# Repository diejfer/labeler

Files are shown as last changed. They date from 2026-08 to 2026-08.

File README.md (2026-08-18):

# Labeler CNC - ESP32 DevKit V1

Control CNC de dos drivers STEP/DIR y un servo RC basado en FluidNC 4.0.3.

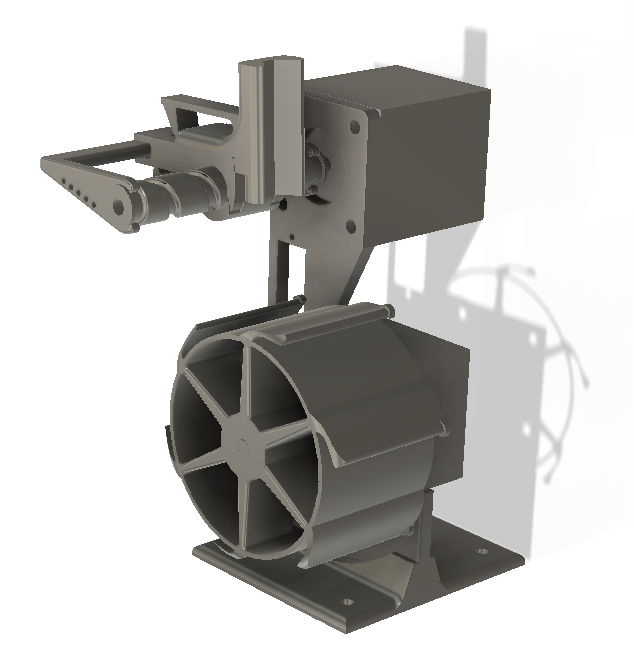
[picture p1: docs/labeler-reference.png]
Vista de referencia de la impresora de etiquetas


Esta es una impresora/plotter de etiquetas de dos ejes: X arrastra la cinta, Y
desplaza el marcador transversalmente y un servo lo apoya o lo separa. Este
repositorio contiene el firmware, la configuración del ESP32 y la aplicación
web que genera y envía el G-code.

## Demostración

Reproducir una demostración del Labeler en YouTube (https://youtu.be/mnnyJeXbWnY)

Hacer clic en la imagen para ver el breve video de la máquina en funcionamiento.

El proyecto PlatformIO activo está en `firmware/FluidNC`. El sketch Arduino
experimental anterior fue retirado para evitar cargar accidentalmente un
firmware sin planificador CNC.

## Estructura

- `firmware/FluidNC`: código fuente fijado a FluidNC v4.0.3.
- `firmware/esp32-data/config.yaml`: configuración de los ejes X, Y y A.
- `hardware/printable`: piezas STL listas para preparar en el laminador.
- `github-pages`: assets HTML, CSS y JavaScript para GitHub Pages.

## Piezas imprimibles

Los modelos exportados para impresión 3D están en `hardware/printable`:

- [`carroYinferior.stl`](hardware/printable/carroYinferior.stl)
- [`carroYsuperior.stl`](hardware/printable/carroYsuperior.stl)
- [`portalapiz.stl`](hardware/printable/portalapiz.stl)
- [`ejeZ.stl`](hardware/printable/ejeZ.stl)
- [`ejeY.stl`](hardware/printable/ejeY.stl)
- [`pie.stl`](hardware/printable/pie.stl)
- [`soportegeneral.stl`](hardware/printable/soportegeneral.stl)
- [`soportemotor.stl`](hardware/printable/soportemotor.stl)
- [`carreteCinta.stl`](hardware/printable/carreteCinta.stl)

Los STL contienen solamente la geometría. Antes de imprimir, revisar en el
laminador la orientación, soportes, relleno y cantidad necesaria de cada pieza
según el material y la impresora disponibles.

La aplicación se publica automáticamente en
`https://diejfer.github.io/labeler`, busca `http://labeler.local` mediante las
APIs REST y no depende de archivos web almacenados en el ESP32.

El navegador debe soportar Local Network Access y conceder permiso a GitHub
Pages para buscar dispositivos en la red local. La implementación apunta a
Chrome/Edge 142 o posterior. El ESP32 y el navegador deben estar en la misma
red Wi-Fi con mDNS habilitado.

La fuente incluida deriva de Hershey Roman Simplex. Los glifos originales
fueron creados por el Dr. A. V. Hershey en el U.S. National Bureau of Standards
y el formato JHF distribuido fue creado por James Hurt, Cognition, Inc. La
licencia y los datos originales están en `github-pages/vendor/hershey`.

También se incluyen Playwrite DE SAS Guides, Orbitron y las cuatro variantes
de Lobster Two desde el repositorio oficial de Google Fonts, bajo SIL OFL 1.1.
Los Material Symbols Outlined y su catálogo de nombres provienen del repositorio
oficial de Google y se distribuyen bajo Apache 2.0. `opentype.js` se utiliza
bajo licencia MIT para transformar los contornos tipográficos en recorridos.
Todas las licencias están junto a sus assets en `github-pages/vendor`.

## Aplicación de etiquetas

La interfaz permite seleccionar cintas de 6, 9, 12, 18, 24, 36 o 45 mm, o ingresar
un ancho particular. Puede generar etiquetas de uno o dos renglones. El texto
se convierte en recorridos mediante Hershey Roman Simplex, una fuente vectorial
estándar de trazo simple para plotters, con mayúsculas y minúsculas. También
permite elegir fuentes OpenType de Google Fonts, cuyos contornos Bézier se
aproximan mediante segmentos de precisión mecánica. El editor permite ajustar
el interlineado y aplicar negrita, cursiva y subrayado tanto a la vista previa
como al G-code, además de buscar e insertar cualquiera de los Material Symbols
Outlined disponibles mediante tokens como `{home}`.

El eje X corresponde al sentido longitudinal de la cinta, Y a su ancho y el eje
A al servo que acerca o aleja el marcador. Antes de imprimir se muestra el
G-code completo para inspección.

Los siguientes datos sólo existen en la pestaña actual del navegador y nunca se
guardan en el ESP32:

- ancho seleccionado;
- formato de uno o dos renglones;
- interlineado y estilos de texto;
- textos de la etiqueta;
- programa G-code generado.

## API persistente

El firmware agrega estos endpoints a FluidNC:

```text
GET  /api/labeler/config
POST /api/labeler/config
```

La configuración se almacena en NVS bajo el espacio `labeler`. Incluye pasos
por milímetro, velocidades máximas, aceleraciones, velocidades de traslado e
impresión, margen, separación de caracteres, posiciones del servo y espera del
servo.

Al abrir una conexión, el cliente aplica la parametría persistente a los ejes X
e Y mediante los ajustes de ejecución de FluidNC. El archivo YAML y los valores
predeterminados de la aplicación usan la relación mecánica documentada debajo.

## Pines

La siguiente tabla es la fuente de verdad para el firmware incluido y coincide
con `firmware/esp32-data/config.yaml`:

| Función | ESP32 | Conectar a |
|---|---:|---|
| Pulso del motor X (arrastre de cinta) | GPIO27 | `STEP` del A4988 X |
| Sentido del motor X | GPIO26 | `DIR` del A4988 X |
| Habilitación del motor X | GPIO14 | `EN` del A4988 X |
| Pulso del motor Y (marcador) | GPIO33 | `STEP` del A4988 Y |
| Sentido del motor Y | GPIO32 | `DIR` del A4988 Y |
| Habilitación del motor Y | GPIO25 | `EN` del A4988 Y |
| Control del servo A | GPIO13 | Señal/PWM del servo |

### Conexionado de cada A4988

Además de STEP, DIR y EN, conectar cada módulo de esta forma:

| Pin del A4988 | Conexión |
|---|---|
| `VDD` | 3V3 del ESP32 |
| `GND` lógico | GND común |
| `VMOT` | Positivo de la fuente de los motores, dentro del rango admitido por el módulo |
| `GND` de potencia | Negativo de la fuente y GND común |
| `RESET` y `SLEEP` | Unir entre sí y llevar a 3V3 |
| `MS1`, `MS2` y `MS3` | 3V3 para seleccionar 1/16 de paso |
| `1A`, `1B` | Una bobina del motor |
| `2A`, `2B` | La otra bobina del motor |

Identificar primero las parejas de bobinas con un multímetro; los colores de
los cables no están estandarizados. Si un eje gira al revés, invertir una de
las bobinas con la alimentación apagada o invertir `direction_pin` en el YAML.
Colocar un capacitor electrolítico de al menos 100 µF entre `VMOT` y GND junto
a cada driver y ajustar el límite de corriente del A4988 antes de mover la
máquina.

El servo se conecta a GPIO13 (señal), a una fuente externa regulada de 5 V y a
GND común. No alimentar el servo desde 3V3 ni conectar VMOT al ESP32. El ESP32,
ambos A4988, la fuente de motores y la fuente del servo deben compartir GND.
No conectar ni desconectar motores o drivers mientras el equipo esté
energizado.

Los drivers X e Y se habilitan automáticamente al comenzar un movimiento y se
deshabilitan al volver a `Idle`, permitiendo mover ambos mecanismos a mano. El
servo permanece energizado para conservar el marcador en la posición alejada.

> **Importante:** los diagramas históricos de `hardware/` y la imagen de pinout
> `docs/esp32-devkit-v1-conexiones.png` corresponden a iteraciones anteriores y
> no coinciden con estos GPIO. Para construir esta versión, usar la tabla
> anterior y `firmware/esp32-data/config.yaml`.

## Calibración inicial

La configuración predeterminada presupone motores de 200 pasos completos por
vuelta (1,8° por paso) y los tres pines MS de cada A4988 en 3,3 V. Eso selecciona
1/16 de paso: `200 × 16 = 3200` pulsos STEP por vuelta. Los valores que trae el
firmware son:

| Eje | Transmisión | Pasos/mm | Pasos/cm |
|---|---|---:|---:|
| X | Rodillo de diámetro fijo 100 mm | 10,1859 | 101,859 |
| Y | Avance lineal de 15 mm por vuelta | 213,3333 | 2133,333 |

Los cálculos usados son `3200 / (π × 100)` para X y `3200 / 15` para Y. Al
conectarse, la aplicación aplica los valores persistentes de NVS sobre la
configuración activa de FluidNC. Para recalibrarlos con medidas reales:

```text
steps_per_mm = pasos_motor_por_vuelta * micropasos / avance_mm_por_vuelta
```

En esa fórmula, `micropasos` es 16 con el conexionado predeterminado. Por
ejemplo, si se cambia el A4988 a paso completo, también hay que recalibrar los
pasos/mm: no alcanza con mover los puentes MS1–MS3.

## Construcción y puesta en marcha

1. Montar la mecánica y comprobar que ambos ejes se muevan libres a mano.
2. Cablear el ESP32, los A4988 y el servo según las tablas anteriores, todavía
   sin insertar los drivers ni conectar los motores.
3. Verificar con un multímetro que no haya cortos y que VDD sea 3,3 V, la
   alimentación del servo sea 5 V y VMOT tenga la tensión prevista.
4. Cortar la alimentación, insertar los A4988 respetando su orientación,
   conectar los motores y ajustar el límite de corriente de cada driver.
5. Compilar y cargar firmware y filesystem como se indica en **Instalación**.
6. Conectar el ESP32 a Wi-Fi, abrir la aplicación publicada y probar primero
   movimientos de 0,1 mm desde **Configuración**.
7. Medir el desplazamiento real, corregir pasos/mm y recién entonces aumentar
   velocidad, aceleración y distancia de prueba.

La pestaña **Configuración** permite probar ambos ejes mediante desplazamientos
relativos de `0,1`, `1` y `10 mm` en los dos sentidos. La interfaz ya no expone
una consola ni una página de control manual.

Actualizar luego `max_rate_mm_per_min`, `acceleration_mm_per_sec2` y
`max_travel_mm` con valores reales de la máquina.

El servo es el eje A. FluidNC usa el rango interno A=-180..0 y la interfaz lo
traduce a 0..180 grados.

La configuración web permite indicar la holgura mecánica de X e Y en
milímetros. Cuando el generador detecta una inversión, agrega un movimiento
relativo exclusivo para tomar esa holgura y restaura la coordenada lógica con
`G92` antes de continuar el trazo. Un valor de `0` desactiva la compensación.

## Instalación

Desde `firmware/FluidNC`:

```powershell
platformio run -e wifi
platformio run -e wifi -t upload
```

Para construir y cargar el sistema de archivos con `config.yaml`:

```powershell
platformio run -e wifi -t buildfs
platformio run -e wifi -t uploadfs
```

También pueden cargarse ambos archivos desde el administrador web de FluidNC.
Reiniciar el controlador después de cargar `config.yaml`.

El filesystem también incluye la WebUI oficial de FluidNC. Si el ESP32 no
puede conectarse a la red configurada, crea el AP `FluidNC` (contraseña
`12345678`) en `http://192.168.4.1`. La página
`http://192.168.4.1/wifi.html` permite escanear redes y guardar un nuevo SSID
y contraseña sin usar USB. Conserva el modo `STA>AP` para mantener este portal
de recuperación cuando falle la conexión configurada.

Al arrancar por primera vez, FluidNC crea su punto de acceso. Para que los
assets externos funcionen, configurar el modo Station con las credenciales de
la red local desde la interfaz de FluidNC.

## Seguridad

La parada desde navegador no reemplaza una parada de emergencia cableada. Antes
de usar el sistema en una máquina real, agregar E-stop y finales de carrera a
pines dedicados y declararlos en `config.yaml`.

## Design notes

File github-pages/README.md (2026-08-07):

# Frontend de Labeler CNC

Esta carpeta se publica directamente en `https://diejfer.github.io/labeler`.
La aplicación busca el controlador en `http://labeler.local` y usa sus APIs
REST, por lo que no necesita cargar HTML, CSS ni JavaScript desde el ESP32.

## Requisitos del navegador

La página solicita permiso para acceder a dispositivos de la red local. La
implementación principal apunta a Chrome/Edge 142 o posterior, donde Local
Network Access permite acceder desde una página HTTPS a un equipo HTTP `.local`.
El ordenador o teléfono y el ESP32 deben estar en la misma red y ésta debe
permitir mDNS.

## Protocolo

- `GET /api/labeler/status`: descubrimiento, estado y posición.
- `GET /api/labeler/command?cmd=...`: una línea G-code con respuesta síncrona.
- `POST /api/labeler/action`: pausa, continuación o reset.
- `GET/POST /api/labeler/config`: parametría persistente.

El cliente envía una línea G-code por vez y espera la respuesta HTTP antes de
continuar. Los datos de la etiqueta sólo viven en la memoria de la página.

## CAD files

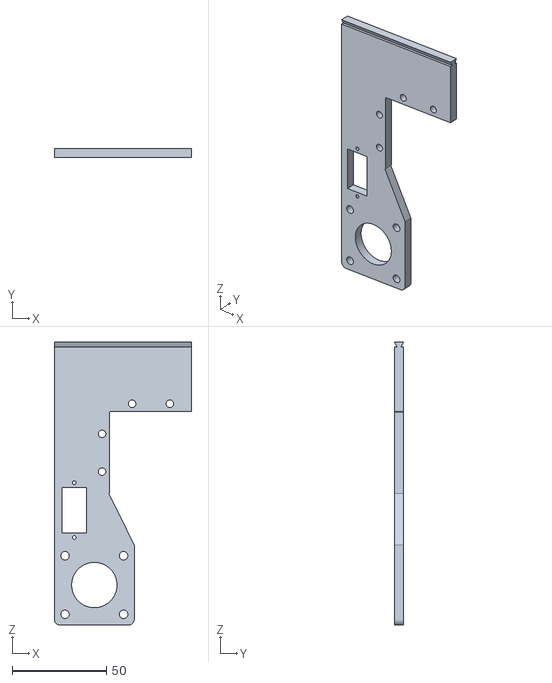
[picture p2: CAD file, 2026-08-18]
hardware/printable/soportegeneral.stl
72.7 x 5.00 x 149.7

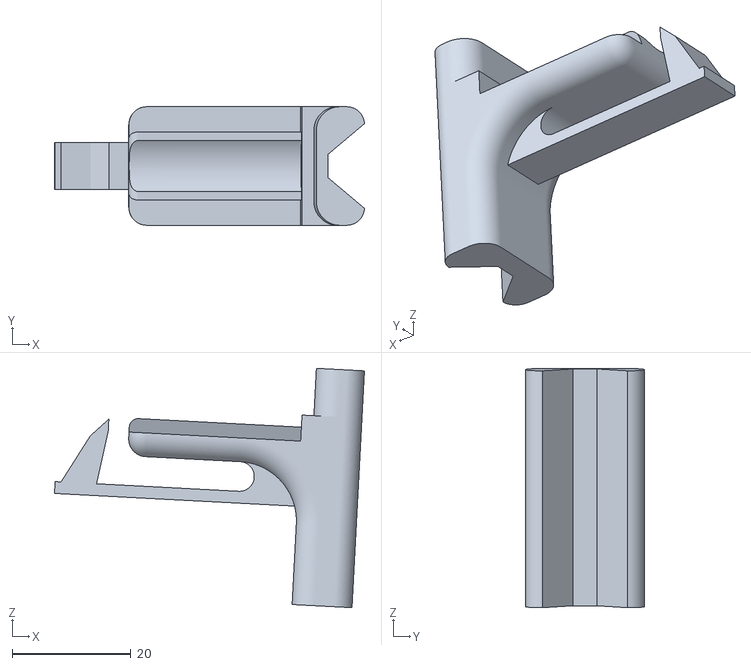
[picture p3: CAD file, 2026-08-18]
hardware/printable/portalapiz.stl
52.3 x 20.0 x 40.4

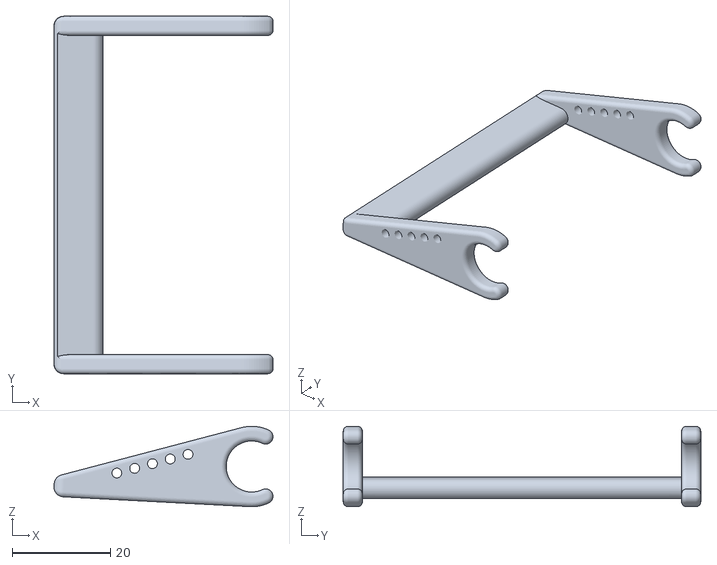
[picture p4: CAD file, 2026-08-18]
hardware/printable/ejeZ.stl
44.7 x 72.9 x 16.4

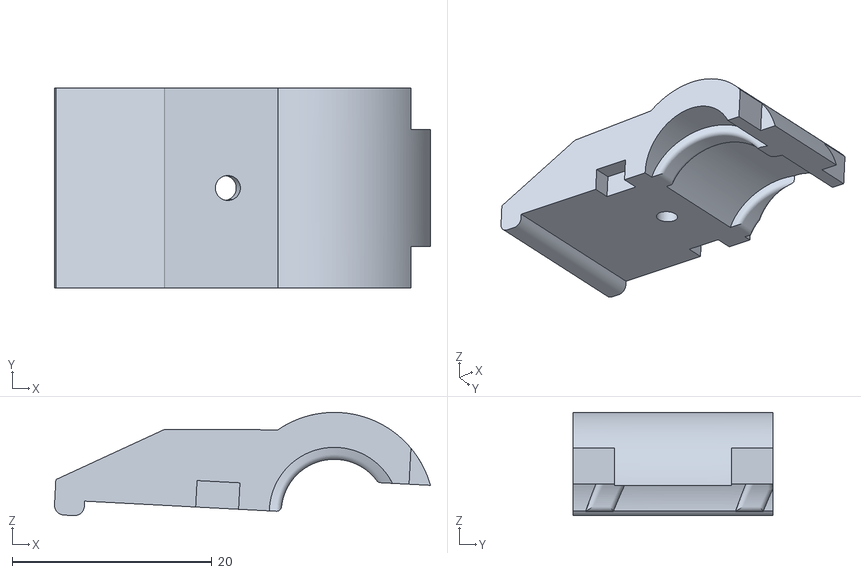
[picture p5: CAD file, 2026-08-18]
hardware/printable/carroYinferior.stl
37.6 x 20.0 x 10.3

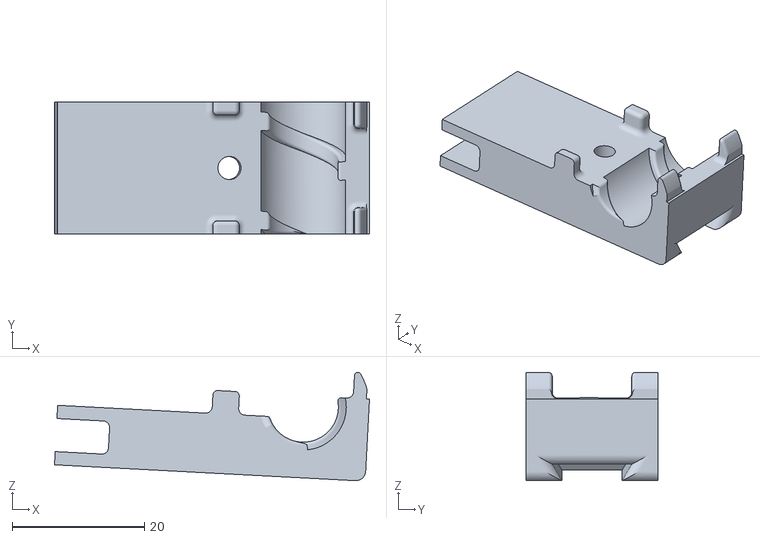
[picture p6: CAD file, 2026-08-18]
hardware/printable/carroYsuperior.stl
47.6 x 20.0 x 16.4

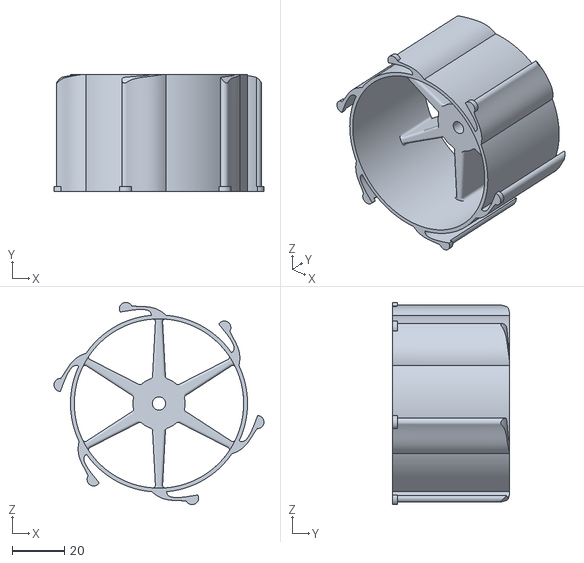
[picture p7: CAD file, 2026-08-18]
hardware/printable/carreteCinta.stl
80.7 x 45.0 x 77.7

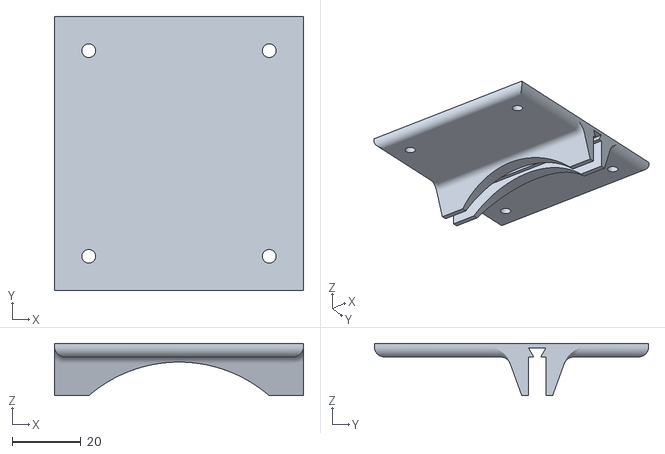
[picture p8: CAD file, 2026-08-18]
hardware/printable/pie.stl
72.7 x 80.0 x 15.3

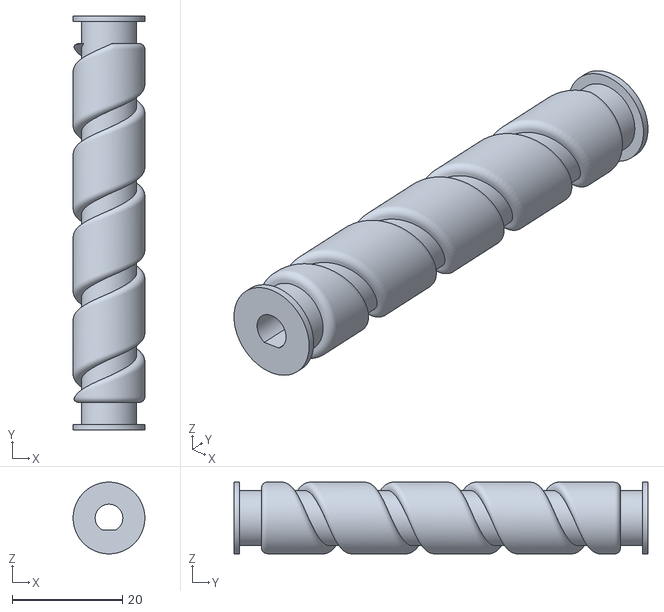
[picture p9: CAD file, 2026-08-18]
hardware/printable/ejeY.stl
13.0 x 75.0 x 13.0

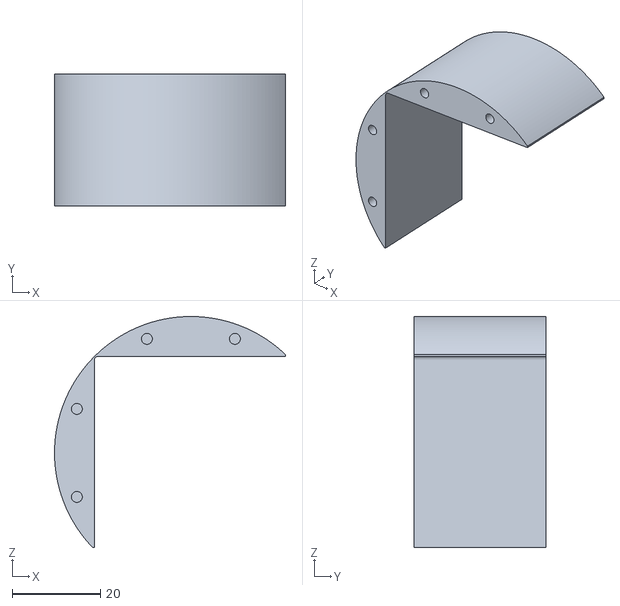
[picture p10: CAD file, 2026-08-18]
hardware/printable/soportemotor.stl
52.5 x 30.0 x 52.5

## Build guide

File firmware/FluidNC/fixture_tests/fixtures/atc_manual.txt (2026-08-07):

; ATC Manual Test Procedure
; Create a config with 2 spindles. First spindle has atc: atc_manual. Second spindle tool_num: 10
; Not compatible with the test fixture program yet.
; single spindle testing
$BYE ; hard reset
$H ; home
$G ; we should see T0
M61 Q1 ; Set tool 1. Nothing should move
$G ; tool should be T1
G0 X0 Y0 ; move to work zero
G38.2 G91 Z-150 F100 P0 ; probe with tool 1 and set z zero
G53 G0 Z-10 ; move up
M3 S12000 ; spindle should turn on
G1 X50 F100; A slow G1 move. Send the next command as soon as possible. Spindle should not stop until move is complete.
M6T2 ; Spindle off, measure current tool, ask for next tool, touch toolsetter, return to work, spindle on
$# ; you should see a TLO value
M6T3 ; Spindle off, Move to change location, ask for new tool, measure it, return to work, spindle on
M61 Q0
$# ; Spindle off, TLO should set to zero
$G ; Tool should be 0 speed should be 12000

; multi spindle testing
M3 ; Spindle on
M6T10 ; Spindle off, spindle changes; 
$G ; Tool 10 and S0
M3S12000; New spindle is on.

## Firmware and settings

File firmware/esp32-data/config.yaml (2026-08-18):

name: "Labeler XY + Servo"
board: "ESP32 DevKit V1"

# Relacion mecanica del diseno compartido:
# Motores de 200 pasos/vuelta, A4988 a 1/16 de paso (3200 pulsos/vuelta).
# X: rodillo de 100 mm de diametro -> 3200 / (pi * 100) = 10.1859 pasos/mm.
# Y: avance de 15 mm/vuelta -> 3200 / 15 = 213.3333 pasos/mm.
stepping:
  engine: RMT
  # Libera X e Y inmediatamente cuando termina el movimiento.
  idle_ms: 0
  pulse_us: 4
  dir_delay_us: 2
  disable_delay_us: 0

axes:
  shared_stepper_disable_pin: NO_PIN

  x:
    steps_per_mm: 10.1859
    max_rate_mm_per_min: 12000.000
    acceleration_mm_per_sec2: 200.000
    max_travel_mm: 1000000.000
    soft_limits: false
    homing:
      cycle: 0
    motor0:
      limit_neg_pin: NO_PIN
      limit_pos_pin: NO_PIN
      limit_all_pin: NO_PIN
      hard_limits: false
      pulloff_mm: 1.000
      stepstick:
        step_pin: gpio.27
        direction_pin: gpio.26
        disable_pin: gpio.14:high

  y:
    steps_per_mm: 213.3333
    max_rate_mm_per_min: 12000.000
    acceleration_mm_per_sec2: 200.000
    max_travel_mm: 1000000.000
    soft_limits: false
    homing:
      cycle: 0
    motor0:
      limit_neg_pin: NO_PIN
      limit_pos_pin: NO_PIN
      limit_all_pin: NO_PIN
      hard_limits: false
      pulloff_mm: 1.000
      stepstick:
        step_pin: gpio.33
        direction_pin: gpio.32
        disable_pin: gpio.25:high

  # FluidNC representa el recorrido de un eje sin homing entre -max_travel
  # y 0. La interfaz traduce 0..180 grados a A-180..A0.
  a:
    steps_per_mm: 1.000
    max_rate_mm_per_min: 3600.000
    acceleration_mm_per_sec2: 180.000
    max_travel_mm: 180.000
    soft_limits: false
    homing:
      cycle: 0
    motor0:
      limit_neg_pin: NO_PIN
      limit_pos_pin: NO_PIN
      limit_all_pin: NO_PIN
      hard_limits: false
      pulloff_mm: 1.000
      rc_servo:
        output_pin: gpio.13
        pwm_hz: 50
        min_pulse_us: 1000
        max_pulse_us: 2000
        timer_ms: 20

control:
  safety_door_pin: NO_PIN
  reset_pin: NO_PIN
  feed_hold_pin: NO_PIN
  cycle_start_pin: NO_PIN
  macro0_pin: NO_PIN
  macro1_pin: NO_PIN
  macro2_pin: NO_PIN
  macro3_pin: NO_PIN

coolant:
  flood_pin: NO_PIN
  mist_pin: NO_PIN
  delay_ms: 0

probe:
  pin: NO_PIN

start:
  must_home: false

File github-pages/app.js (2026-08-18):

const CONTROLLER_URL = 'http://labeler.local';

function localFetch(path, options = {}) {
  return fetch(`${CONTROLLER_URL}${path}`, {
    cache: 'no-store',
    mode: 'cors',
    targetAddressSpace: 'local',
    ...options
  });
}

class FluidNCClient extends EventTarget {
  constructor() {
    super();
    this.online = false;
    this.queue = [];
    this.pending = null;
    this.sent = 0;
    this.total = 0;
    this.statusTimer = null;
    this.completionTimer = null;
    this.status = null;
  }

  emit(name, detail = {}) { this.dispatchEvent(new CustomEvent(name, { detail })); }

  async connect() {
    this.disconnect();
    try {
      await this.pollStatus();
      this.online = true;
      this.emit('connection', { online: true });
      this.statusTimer = setInterval(() => this.pollStatus(), 750);
    } catch (error) {
      this.online = false;
      this.emit('connection', { online: false });
      throw new Error(`No se encontró labeler.local. ${error.message}`);
    }
  }

  disconnect() {
    clearInterval(this.statusTimer);
    clearTimeout(this.completionTimer);
    this.statusTimer = null;
    this.completionTimer = null;
    this.online = false;
  }

  async pollStatus() {
    try {
      const response = await localFetch('/api/labeler/status');
      if (!response.ok) throw new Error(`HTTP ${response.status}`);
      const status = await response.json();
      this.status = status;
      this.emit('status', { state:status.state, positions:[status.x,status.y,0,status.a] });
      return status;
    } catch (error) {
      if (this.online) {
        this.online = false;
        this.emit('connection', { online:false });
      }
      throw error;
    }
  }

  async action(action) {
    const response = await localFetch('/api/labeler/action', {
      method:'POST',
      headers:{ 'Content-Type':'application/x-www-form-urlencoded' },
      body:new URLSearchParams({ action })
    });
    if (!response.ok) throw new Error((await response.text()) || `HTTP ${response.status}`);
  }

  run(program, purpose = 'program') {
    if (!this.online) throw new Error('El controlador no está conectado.');
    if (this.pending || this.queue.length || this.total) throw new Error('Ya hay un envío en curso.');
    const lines = program.split(/\r?\n/).map(line => line.replace(/;.*$/, '').trim()).filter(Boolean);
    if (!lines.length) throw new Error('No hay comandos para enviar.');
    this.queue = lines;
    this.pending = null;
    this.sent = 0;
    this.total = lines.length;
    this.purpose = purpose;
    this.emit('progress', { sent: 0, total: this.total, purpose });
    this.pump();
  }

  async moveServo(angle) {
    if (!this.online) throw new Error('El controlador no está conectado.');
    if (this.pending || this.queue.length) throw new Error('Ya hay un envío en curso.');
    const status = await this.pollStatus();
    if (status.state !== 'Idle') throw new Error(`La máquina está en estado ${status.state}.`);
    const target = servoAxis(angle);
    const delta = fmt(target - status.a);
    if (Math.abs(delta) < 0.001) {
      this.emit('log', { text:`El servo ya está en ${angle}°.` });
      return;
    }
    this.run(`G91\nG0 A${delta} F3600\nG90`, 'manual');
  }

  async jogServo(deltaAngle) {
    if (!this.online) throw new Error('El controlador no está conectado.');
    if (this.pending || this.queue.length) throw new Error('Ya hay un envío en curso.');
    const status = await this.pollStatus();
    if (status.state !== 'Idle') throw new Error(`La máquina está en estado ${status.state}.`);
    const currentAngle = status.a + 180;
    const targetAngle = Math.max(0, Math.min(180, currentAngle + deltaAngle));
    const delta = fmt(targetAngle - currentAngle);
    if (Math.abs(delta) < 0.001) {
      this.emit('log', { text:`El servo alcanzó el límite de ${targetAngle}°.` });
      return;
    }
    this.run(`G91\nG0 A${delta} F3600\nG90`, 'manual');
  }

  async jogAxis(axis, distanceMm, maxSpeedMmS) {
    if (!this.online) throw new Error('El controlador no está conectado.');
    if (this.pending || this.queue.length) throw new Error('Ya hay un envío en curso.');
    const status = await this.pollStatus();
    if (status.state !== 'Idle') throw new Error(`La máquina está en estado ${status.state}.`);
    if (!Number.isFinite(distanceMm) || distanceMm === 0) throw new Error('La distancia debe ser distinta de cero.');
    const distance = fmt(distanceMm);
    const feed = fmt(Math.min(maxSpeedMmS, 10) * 60);
    this.run(`G91\nG1 ${axis}${distance} F${feed}\nG90`, 'manual');
  }

  async zeroAxis(axis) {
    if (!this.online) throw new Error('El controlador no está conectado.');
    if (this.pending || this.queue.length) throw new Error('Ya hay un envío en curso.');
    const status = await this.pollStatus();
    if (status.state !== 'Idle') throw new Error(`La máquina está en estado ${status.state}.`);
    this.run(`G92 ${axis}0`, 'manual');
  }

  async pump() {
    if (this.pending || !this.online) {
      return;
    }
    if (!this.queue.length) {
      this.scheduleCompletionCheck();
      return;
    }
    const batch = [];
    let batchLength = 0;
    while (this.queue.length && batch.length < 12) {
      const next = this.queue[0];
      const nextLength = next.length + (batch.length ? 1 : 0);
      if (batch.length && batchLength + nextLength > 220) break;
      batch.push(this.queue.shift());
      batchLength += nextLength;
    }
    this.pending = batch;
    batch.forEach(line => this.emit('log', { text: `> ${line}` }));
    try {
      const response = await localFetch('/api/labeler/command', {
        method:'POST',
        headers:{ 'Content-Type':'application/x-www-form-urlencoded' },
        body:new URLSearchParams({ program:batch.join('\n') })
      });
      const text = (await response.text()).trim();
      if (response.status === 503) {
        this.queue.unshift(...batch);
        this.pending = null;
        setTimeout(() => this.pump(), 150);
        return;
      }
      if (!response.ok || /(^|\n)(error:|ALARM:)/i.test(text)) throw new Error(text || `HTTP ${response.status}`);
      this.pending = null;
      this.sent += batch.length;
      this.emit('progress', { sent:this.sent, total:this.total, purpose:this.purpose });
      this.pump();
    } catch (error) {
      this.pending = null;
      this.queue = [];
      this.total = 0;
      this.emit('failure', { response:error.message, purpose:this.purpose });
    }
  }

  scheduleCompletionCheck() {
    if (this.completionTimer || !this.total) return;
    this.completionTimer = setTimeout(() => this.checkCompletion(), 200);
  }
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

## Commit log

2026-08-07 Initial ESP32 labeler firmware and web interface
    [4x_2209_atc.yaml, 4x_2209_atc_class.yaml, 4x_2209a_atc_class.yaml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]
2026-08-08 Fix web servo controls and G-code API
    [app.js]
2026-08-08 Add manual stepper calibration controls
2026-08-08 Batch web G-code commands for reliable printing
2026-08-09 Add configurable XY backlash compensation
    [app.js]
2026-08-09 Release XY motors while controller is idle
2026-08-09 Add Google outline fonts and Material Symbols
2026-08-09 Add 45 mm standard tape width
2026-08-09 Fix continuous Playwrite font rendering
    [app.js]
2026-08-18 Configura mecánica y simplifica la web (#1)
    Documenta y configura la relación mecánica, agrega configuración Wi-Fi, mueve las pruebas de ejes a milímetros y elimina el control manual.
2026-08-18 Documenta construcción y agrega modelos 3D
    [carreteCinta.stl, carroYinferior.stl, carroYsuperior.stl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]
